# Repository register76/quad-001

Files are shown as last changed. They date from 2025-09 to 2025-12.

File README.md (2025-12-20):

<p align="center">
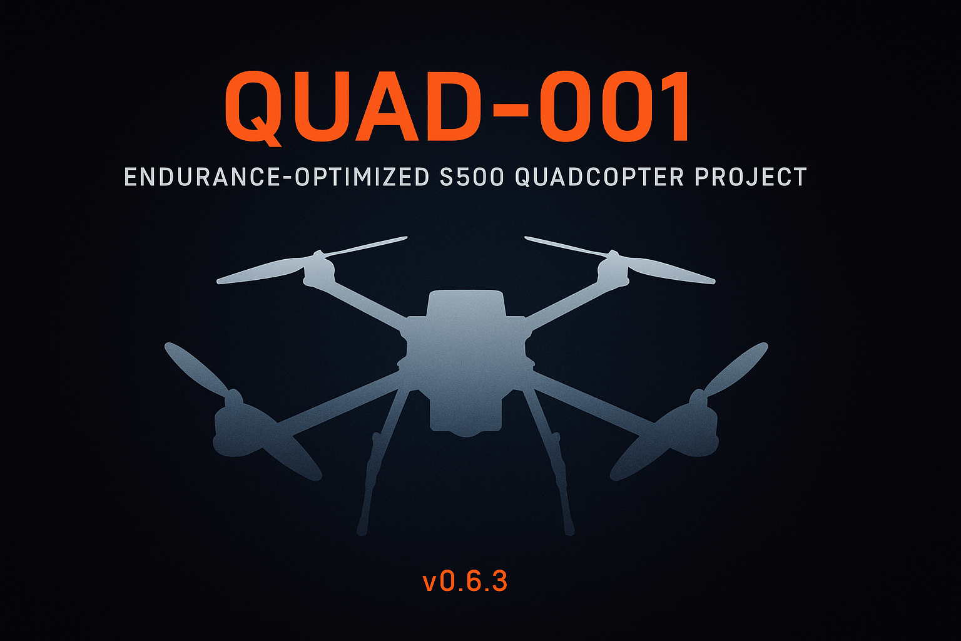
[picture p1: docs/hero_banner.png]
Quad-001 Hero Banner
  
</p>

<p align="center">
  
  
  
</p>

# Quad-001 — Endurance-Optimized S500 Quadcopter  
Version: **v0.6.3** (December 2025)

Quad-001 is a long-term engineering project to design, build, tune, and document a
high-efficiency 450–500 mm class quadcopter focused on endurance, stability,
and modular expandability. The project includes CAD parts, firmware configuration,
structural tuning, telemetry integration, and future autonomy and FPV improvements.

---

## 🛠️ Current Configuration (v0.6.3)

**Airframe**
- S500 frame (final decision locked)
- Carbon-fiber stiffeners + TPU/PLA vibration isolation
- Custom 4-piece landing-leg damper system
- New landing leg installed

**Propulsion**
- Motors: 3112-900 KV  
- Props: **APC 10 × 4.7** (current set installed)  
- Battery: 4S 5000 mAh LiPo  
- ESC: SkyStars KO60 BLHeli32 60A 4-in-1

**Flight Control**
- Matek H743-SLIM V3  
- GPS/Compass: HGLRC M100  
- Receiver: ExpressLRS RP4TD  
- Telemetry: **RFD900X** (MAVLink2, SERIAL6 @ 57 600 baud)

**Cameras / FPV (coming in v0.7)**
- Foxeer Razer Micro FPV camera  
- TBS Unify Pro32 HV VTX  
- Foxeer Lollipop Antenna  
- **RunCam Orange 5** (4K high-resolution recording camera)

---

## 🔗 Quick Component Reference (Web Links)

| Component | Model / Notes | Link |
|---|---|---|
| **Frame** | S500 500 mm frame | https://www.amazon.com/s?k=S500+frame |
| **Motors** | 3112-900KV | https://www.amazon.com/s?k=3112+900kv+motor |
| **Props** | APC 10×4.7 SF | https://www.apcprop.com/product/10x4-7sf-b4/ |
| **ESC** | Skystars KO60 4-in-1 BLHeli32 | https://www.amazon.com/s?k=skystars+ko60 |
| **Flight Controller** | Matek H743-SLIM V3 | http://www.mateksys.com/?portfolio=h743-slim |
| **GPS / Compass** | HGLRC M100 | https://www.hglrc.com/products/hglrc-m100-mini-m8n-gps |
| **Receiver** | ExpressLRS RP4TD | https://www.expresslrs.org/receivers/rp4td/ |
| **Transmitter (RC)** | Radiomaster Boxer | https://www.radiomasterrc.com/products/boxer-radio-controller |
| **Telemetry Radio** | RFD900X | https://store.rfdesign.com.au/rfd-900x/ |
| **FPV Camera** | Foxeer Razer Micro | https://www.foxeer.com/foxeer-mini-standard-razer-fpv-camera-g-266 |
| **VTX** | TBS Unify Pro32 HV | https://team-blacksheep.com/shop/pro32hv |
| **Antenna** | Foxeer Lollipop | https://www.amazon.com/s?k=foxeer+lollipop |
| **HD Camera** | **RunCam Orange 5** | https://shop.runcam.com/runcam-5-orange/ |
| **Companion Computer** | Rpanion (Pi-based) | https://www.rpanion.com/software/rpanion-server/ |
| **ArduPilot Firmware** | ArduCopter | https://firmware.ardupilot.org/Copter/stable/ |

---

## 🚁 Project Status Summary

Quad-001 is structurally complete and in the late-tuning phase for v0.6.x:

- New APC 10×4.7 props installed  
- All 4 dampers + new landing leg installed  
- First stable flight on 10×4.7 completed (v0.6.3 milestone)  
- RFD900X MAVLink link fully operational  
- Initial FFT analysis complete (fundamental ~86 Hz)  
- Preparing for notch tuning, altitude-loop refinement, and rate-loop steps

The aircraft is now optimized for clean logs and ready for advanced tuning.

---

## 🧪 Tuning Progress (v0.6.x)

**Completed**
- Hover tests with 10×4.7 props  
- Initial FFT → fundamental ~86 Hz  
- Basic position hold tuning  
- RFD900 integration for live tuning  
- Leg dampers & structural stiffening  
- Baseline logs for rate loops and altitude behavior  

**Upcoming**
- Update harmonic notch filter using new FFT  
- Altitude-loop refinement  
- Step-response rate-loop flights  
- Autotune  
- Post-Autotune filter + PID verification  

---

## 🎥 FPV Integration (v0.7 milestone)

Planned tasks:
- Wire Foxeer camera → H743  
- Install TBS Unify Pro32 HV  
- Install and tune Lollipop antenna  
- Noise + EMI validation  
- Ground station receiver testing  
- Action cam mounting tests for **RunCam Orange 5**

---

## 🧭 Autonomy & Sensors (v0.8 milestone)

- Downward LiDAR (TF-Luna I2C preferred)  
- Enhanced altitude hold  
- AUTO missions  
- RTL refinement  
- Speed-limit switches via PSC_ANGLE_MAX  
- Companion-computer extensions (Rpanion, MAVLink routing, future apps)

---

## 🧱 CAD / Mechanical Design

Custom-designed and parametric components include:

- Arm stiffeners (TPU → CF → PLA sandwich)  
- Landing gear dampers  
- GPS mast  
- Battery tray  
- RFD900 mounting hardware  
- Prop guard experiments for 1047 props  
- Camera mount designs, including **RunCam Orange 5** mounting options  

---

## 🎯 Roadmap

**v0.6.x — Structural & Tuning**
- ✔ Frame upgrade  
- ✔ RFD900 integration  
- ✔ New props + dampening  
- ✔ Notch tuning  
- ✔ Rate/altitude tuning  
- ☐ Autotune  

**v0.7 — FPV**
- ✔ Camera + VTX integration  
- ✔ Antenna work  
- ✔ Ground station receiver  
- ☐ Wiring cleanup  
- ☐ RunCam mount + test flights  

**v0.8 — Autonomy**
- ☐ Downward LiDAR  
- ☐ AUTO missions  
- ☐ Advanced RTL  
- ☐ Speed limits  
- ☐ Companion-computer apps  

---

## 🧵 Serial Ports

### 🧭 Matek H743-SLIM UART Reference Guide

[H743-SLIM V3 IO Mapping Documentation](https://www.mateksys.com/?portfolio=h743-slim#tab-id-5)

| **GPIO Port Label** | **FC PAD LABEL** | **Typical Use** | **ArduPilot SERIALx** | **Protocol (value)** | **Baud** | **Notes / Tips** |
|---|---|---|---|---|---|---|
| **USART1** | RX1/TX1 | 📈 Spare  | SERIAL2 | None (0) |  | Leave unused until you need it (set to device-specific later). |
| **USART2** | RX2/TX2 | 📡 GPS #1 | SERIAL3 | GPS (5)  | 230 | Pair with I²C compass on same GPS puck. |
| **USART3** | RX3/TX3 | 📈 Spare  | SERIAL4 | None (0) | | Leave unused until you need it (set to device-specific later). |
| **UART4**  | RX4/TX4 | 🛰 Telemetry / RFD900 | SERIAL6 | MAVLink (2) | 57 | Long-range radio. Provide dedicated 5 V ≥ 2 A BEC. |
| **USART6** | RX6/TX6 |  📈 Spare | SERIAL7 | None (0) |  | Leave unused until you need it (set to device-specific later).  |
| **UART7** | RX7/TX7 | 🎮 ELRS Receiver (CRSF) | SERIAL1 |  ELRS(23) | 420 | Express LRS (main receiver port). |
| **UART8** | RX8/TX8 | ESC Telemetry | SERIAL5 |  ESC Telemetry(16) | 115 | ESC Telemetry. |
| **USB**  | USB | 🔌 Ground Station | SERIAL0 | MAVLink (2) |  | Main setup + firmware loading port. |

---

## 📄 License

See `LICENSE` for details.

---

## ✨ Notes

Quad-001 is a long-term iterative engineering project.  
All CAD, firmware, wiring, and tuning details evolve alongside each milestone.

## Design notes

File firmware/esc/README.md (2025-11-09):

# ESC

This is the paramter files for ESC  

## How to program ESC
- Goto https://esc-configurator.com/
- Plug USB cable into FC or connect through RFD900
- Ensure SERVO_BLH_AUTO = 1 in Mission Planner Parameters
- Select COM port in esc-configurator.com

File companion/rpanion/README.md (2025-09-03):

# Rpanion Link

This project uses **Rpanion-Server** as the companion computer software for telemetry and video streaming on the Raspberry Pi.  

👉 Download the release version 0.11.0 for Raspberry Pi 3, 4, and ZERO2 here: [Rpanion-Server Release v0.11.0](https://github.com/stephendade/Rpanion-server/releases/download/v0.11.0/Rpanion-Server-0.11.0-RasPiOS.img.xz)

---

## Notes
- Tested with Raspberry Pi 3/4 and Pi Zero 2 W.  
- Integrates with ArduPilot over MAVLink.  
- Provides telemetry, video streaming, and WiFi hotspot functionality.  

For setup instructions, see the official [Rpanion source and documentation](https://github.com/stephendade/Rpanion-server).

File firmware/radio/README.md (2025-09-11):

# RadioMaster Boxer Backup

- Radio: RadioMaster Boxer
- EdgeTX: 2.x.x
- Protocol: CRSF (ExpressLRS)
- ELRS TX FW: x.y.z
- ELRS RX FW: x.y.z
- Typical Packet Rate: 250 Hz
- Model Match: (on/off)

## Contents
- `MODELS/` — model configs
- `RADIO/` — global radio settings
- `backups/boxer-backup.otx` — full EdgeTX Companion backup (optional)

## Restore
1. Copy `MODELS/` and `RADIO/` to SD card root, or
2. Use Companion → open `.otx` → Write to Radio.

⚠️ Binding phrase and Wi-Fi creds are not included for security.

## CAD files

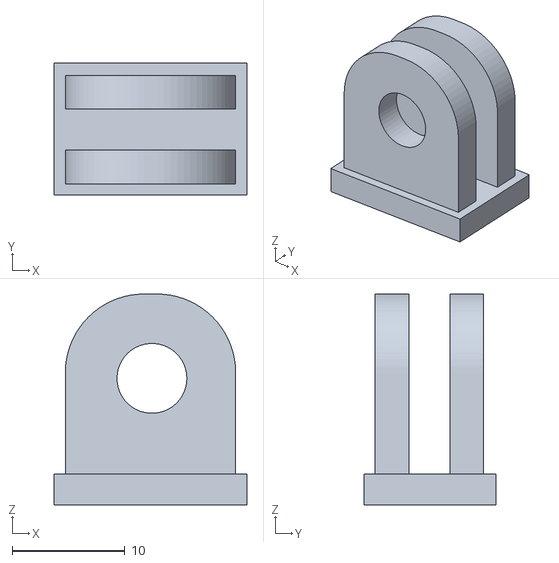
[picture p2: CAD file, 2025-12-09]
cad/openscad/2_prong.stl
17.1 x 11.8 x 18.8

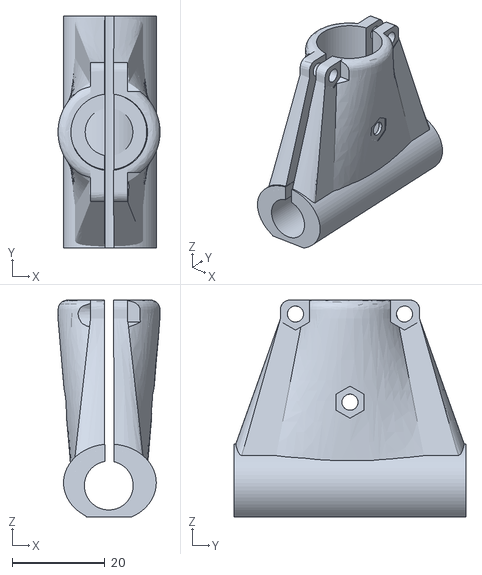
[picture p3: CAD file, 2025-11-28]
cad/stl/Landing_Gear_Tee_Remix.stl
22.0 x 50.0 x 46.7

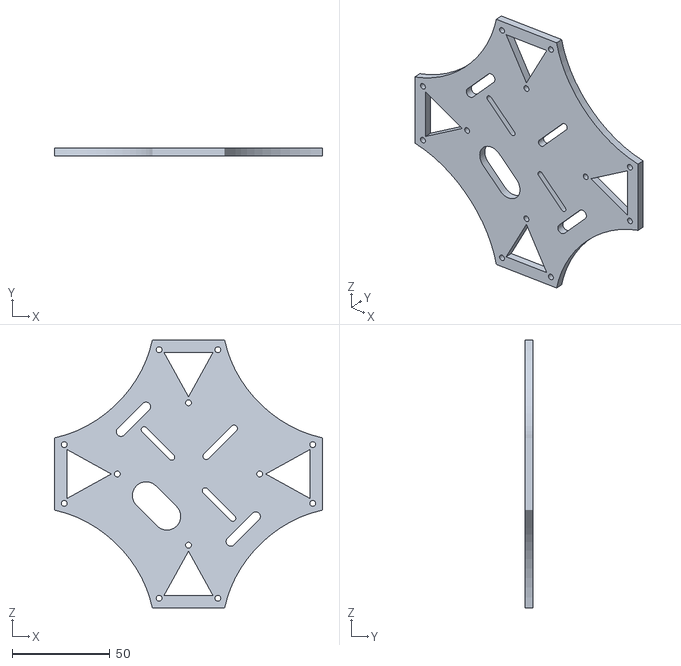
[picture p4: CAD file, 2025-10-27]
cad/openscad/top_frame_s500.STL
137.0 x 4.00 x 136.9

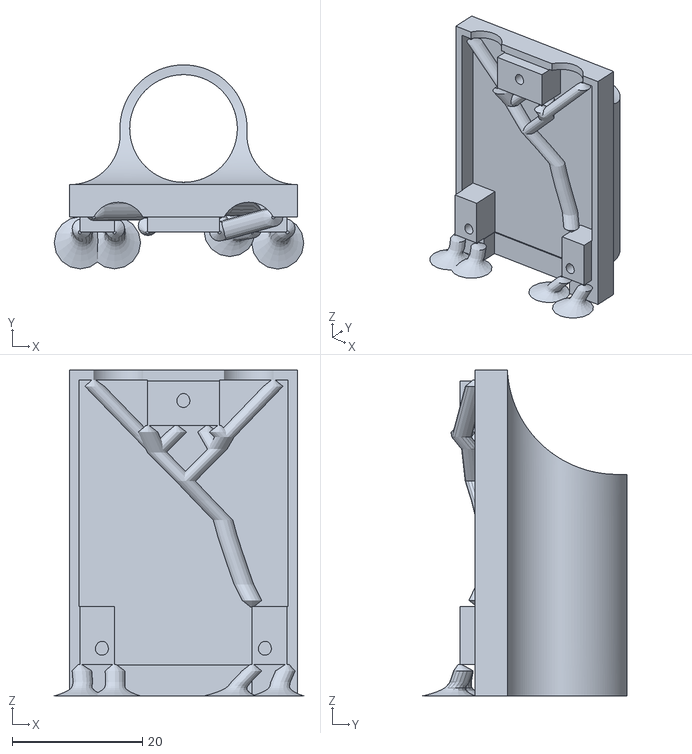
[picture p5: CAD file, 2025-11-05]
cad/stl/RFD900_16mm.stl
38.3 x 31.3 x 50.0

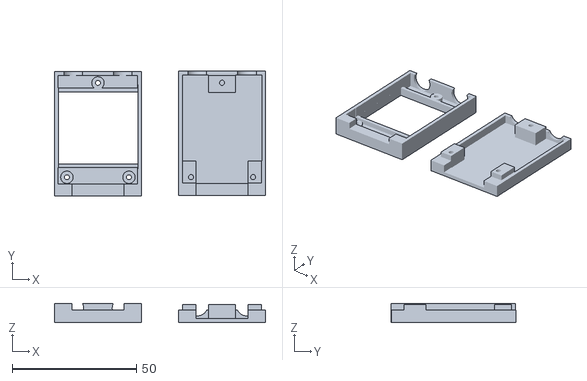
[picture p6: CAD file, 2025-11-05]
cad/stl/rfd900test.stl
85.0 x 50.2 x 7.75

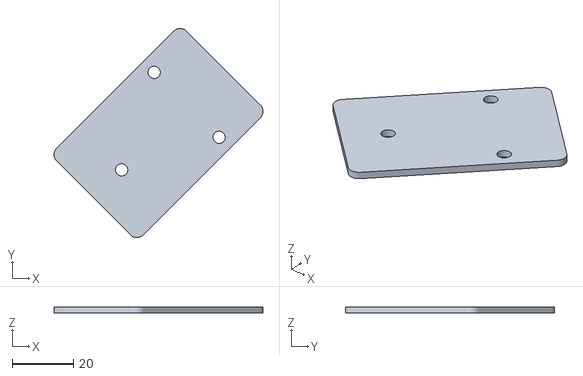
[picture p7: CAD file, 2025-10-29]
cad/stl/s500_cf_doublers.stl
68.2 x 68.2 x 2.00

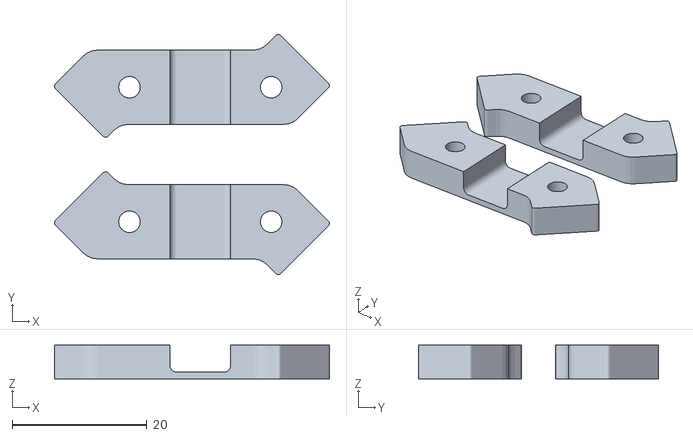
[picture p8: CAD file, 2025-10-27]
cad/stl/S500_Spacerv4.stl
40.7 x 35.6 x 5.00

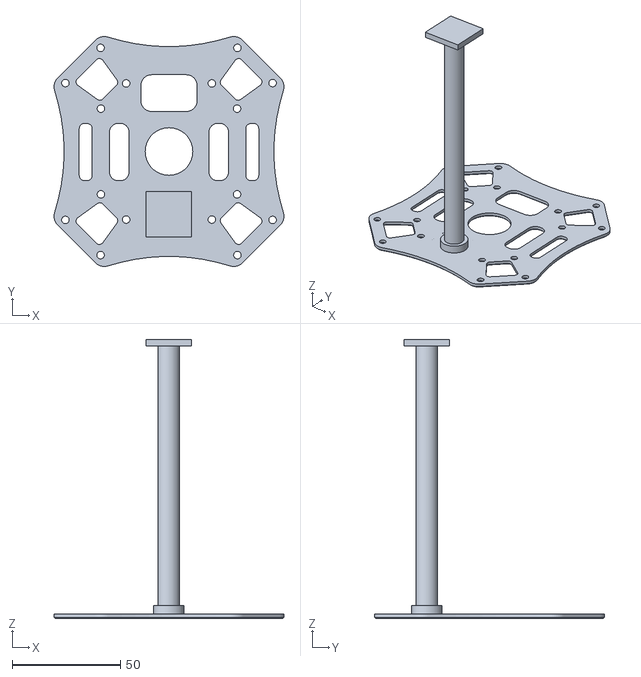
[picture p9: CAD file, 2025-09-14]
cad/stl/quad-001-union-mast-frame.stl
106.3 x 106.3 x 129.0

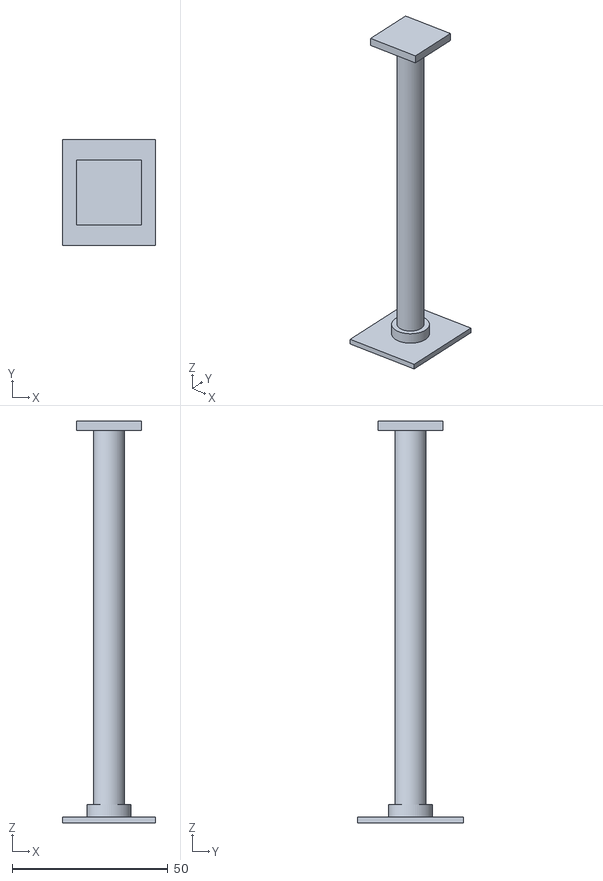
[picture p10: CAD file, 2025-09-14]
cad/stl/quad-001-gps_mast.stl
30.0 x 34.0 x 129.0

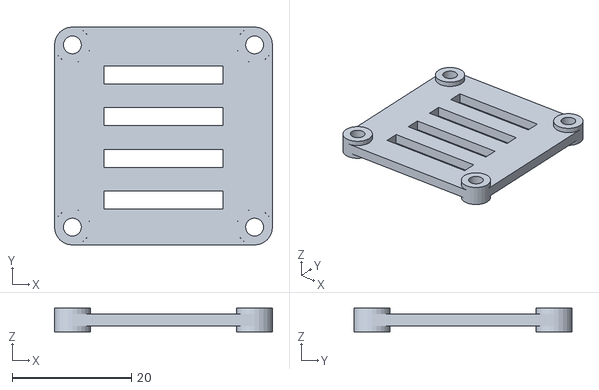
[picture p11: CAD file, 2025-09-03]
cad/stl/Flight_controller_mount_30x30_2-6.stl
36.5 x 36.5 x 4.00

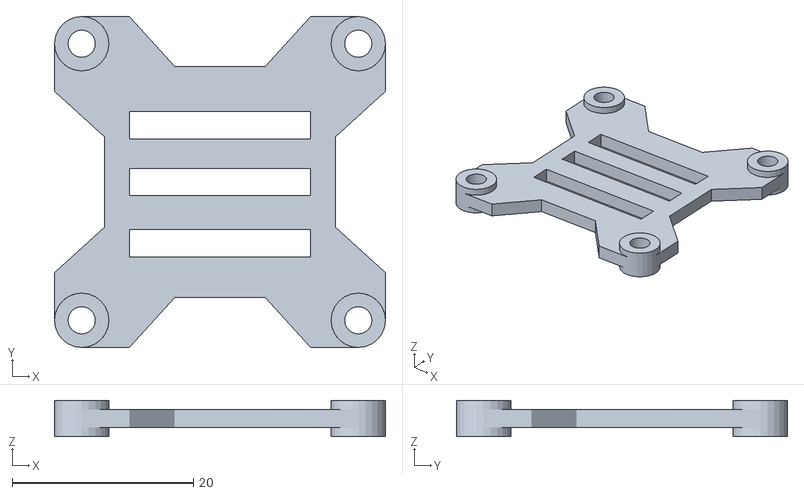
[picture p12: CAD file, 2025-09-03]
cad/stl/Flight_controller_mount_30x30_4-6.stl
36.5 x 36.5 x 4.00

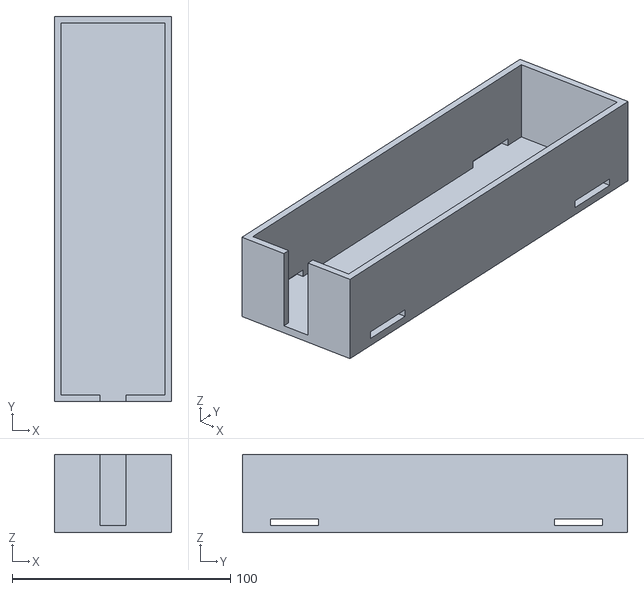
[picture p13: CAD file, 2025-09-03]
cad/stl/quad-001-battery_tray.stl
53.6 x 176.6 x 35.8

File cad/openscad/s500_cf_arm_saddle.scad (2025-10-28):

//
// S500 Arm Saddle (Bolt-On) — OpenSCAD
// Author: ChatGPT
// Version: v0.1 (2025-10-28)
// Purpose:
//   Two flat CF plates (top & bottom) that clamp the arm root using the existing 4-hole pattern.
//   Cut from 2.0 mm carbon fiber. No epoxy needed. Improves torsional stiffness.
//   Export each plate as DXF for CNC or print PLA first as a fit template.
//
// -------------------- User Parameters --------------------

export_mode       = "3D";   // "3D" or "DXF" (DXF outputs 2D outlines+holes only)
show_all_arms     = true;   // true: preview all four; false: preview one (arm_index)
arm_index         = 0;      // which arm to show when show_all_arms=false (0..3)

// Plate geometry
cf_thickness      = 2.0;    // mm
plate_len         = 60;     // mm (along arm axis)
plate_wid         = 40;     // mm (across arm axis)
corner_r          = 3.0;    // mm fillet for corners
kerf              = 0.10;   // mm (+ grows outline) for CNC compensation

// Holes (M3 recommended)
hole_d            = 4.0;    // mm (loose fit). If you want tighter, set to 3.2
slot_enable       = false;  // true -> slots in long direction
slot_d            = 3.2;    // slot width
slot_len          = 5.0;    // slot extra length (overall ~ hole_d + slot_len)

// Arm relief pocket (shallow recess on the inner face to hug the arm crown slightly)
relief_enable     = true;
relief_len        = 36;     // mm along arm
relief_wid        = 18;     // mm across arm
relief_depth      = 0.5;    // mm depth (keeps plate nearly full strength)
relief_round_r    = 2.0;    // corner fillet of relief

// Placement (reused from your good fit)
r_patch           = 50;                 // distance from board origin to plate center
arm_angles        = [45, 135, 225, 315];

// Hole pattern (XY offsets relative to plate center BEFORE rotation)
pattern_arm0      = [[-14,0],[13,-15],[13,15],[-13,0]];
pattern_arm1      = pattern_arm0;
pattern_arm2      = pattern_arm0;
pattern_arm3      = pattern_arm0;

// Optional: reference STL (for visual alignment only)
show_stl          = false;              // set true if you want to overlay your frame STL
stl_path          = "top_frame_s500.STL";
stl_alpha         = 0.25;
stl_rotate_deg    = [90,0,45];          // your earlier good orientation
stl_translate     = [-97.5, 0, 0];
stl_scale         = 1.0;

// -------------------- Helpers --------------------

function sel_pattern(i) =
    i==0 ? pattern_arm0 :
    i==1 ? pattern_arm1 :
    i==2 ? pattern_arm2 :
           pattern_arm3 ;

module rounded_rect_2d(w, h, r) {
    // Kerf in/out to keep fillets clean
    offset(delta=kerf) offset(delta=-kerf)
    hull() {
        translate([ w/2 - r,  h/2 - r]) circle(r=r, $fn=48);
        translate([-w/2 + r,  h/2 - r]) circle(r=r, $fn=48);
        translate([ w/2 - r, -h/2 + r]) circle(r=r, $fn=48);
        translate([-w/2 + r, -h/2 + r]) circle(r=r, $fn=48);
    }
}

module relief_2d(L, W, r) {
    // filleted inner pocket
    hull() {
        translate([ L/2 - r,  W/2 - r]) circle(r=r, $fn=36);
        translate([-L/2 + r,  W/2 - r]) circle(r=r, $fn=36);
        translate([ L/2 - r, -W/2 + r]) circle(r=r, $fn=36);
        translate([-L/2 + r, -W/2 + r]) circle(r=r, $fn=36);
    }
}

module hole_2d(d)    { circle(d=d, $fn=36); }
module slot_2d(d, L) {
    // Capsule slot along X
    hull() {
        translate([+L/2 - d/2, 0]) circle(d=d, $fn=36);
        translate([-L/2 + d/2, 0]) circle(d=d, $fn=36);
    }
}

module holes_2d(points) {
    for (p = points) translate(p)
        if (slot_enable) slot_2d(slot_d, hole_d + slot_len);
        else             hole_2d(hole_d);
}

// One plate outline with holes; if relief is enabled, subtract shallow recess on the "inner" face.
// We'll build TOP and BOTTOM from the same 2D and just extrude; relief direction is documented in notes.
module saddle_plate_2d(hole_pts) {
    difference() {
        rounded_rect_2d(plate_len, plate_wid, corner_r);
        holes_2d(hole_pts);
        if (relief_enable) // carve an internal pocket area
            relief_2d(relief_len, relief_wid, relief_round_r);
    }
}

module saddle_plate_3d(hole_pts) {
    linear_extrude(height=cf_thickness)
        saddle_plate_2d(hole_pts);
}

// Render one arm's top+bottom at its frame position
module arm_saddle_set(i) {
    angle = arm_angles[i];
    pts   = sel_pattern(i);
    // Position at arm root
    rotate([0,0,angle]) translate([r_patch,0,0]) {
        // TOP plate (put relief DOWN toward arm)
        color("black") translate([0,0, cf_thickness]) mirror([0,0,1]) saddle_plate_3d(pts);

        // BOTTOM plate (put relief UP toward arm)
        color("black") saddle_plate_3d(pts);

        // Optional visual markers:
        // translate([0,0,cf_thickness*1.8]) color([0,1,0]) cylinder(h=0.1,d=2,$fn=24); // plate center dot
    }
}

module all_saddles() {
    for (i=[0:len(arm_angles)-1]) arm_saddle_set(i);
}

module ref_stl() {
    color([0.1,0.6,1.0, stl_alpha])
        translate(stl_translate) rotate(stl_rotate_deg) scale(stl_scale)
            import(stl_path, convexity=5);
}

// -------------------- Scene --------------------

if (export_mode == "DXF") {
    // DXF export: choose TOP or BOTTOM—same outline; relief pocket shows so CAM can engrave 0.5 mm depth if desired.
    // Comment/uncomment the one you want to export at a time:
    projection(cut=true) saddle_plate_2d(pattern_arm0);
} else {
    if (show_stl) ref_stl();
    if (show_all_arms) {
        all_saddles();
    } else {
        arm_saddle_set(arm_index);
    }
}

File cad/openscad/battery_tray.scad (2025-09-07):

//
// Parametric battery tray with SIDE-WALL strap slots
// B Dog — Pi/quad build
//
// Coordinate frame:
//   X = width  (left↔right)
//   Y = length (front↔back)
//   Z = up (floor → lips)
//

//-------------------
// USER PARAMETERS 
//-------------------
battery           = [47, 170, 32];   // [W, L, H]  (width, length, height) in mm
clearance         = 0.30;            // per-side clearance inside pocket (ABS ≈ 0.3–0.4)
wallThickness     = 3.00;            // wall thickness
floorThickness    = 3.20;            // floor thickness

// Side-wall strap slots (two bands)
strapWidth       = 20.0;                // strap width (typical 20 mm)
slotLengthY      = strapWidth + 2.0;    // along Y (give ~1 mm per side)
slotThicknessZ   = 3.0;                 // vertical opening (Z) for the strap thickness
slot1OffsetFront = 10.0;                // first slot center from inner FRONT (Y)
slotSpacingY     = 130.0;               // distance between the two slots along Y

// Cable exit notch (front lip)
cableNotchWidth = 12.0;
cableNotchDepth = 6.0;

//-----------------------
// DERIVED GEOMETRY
//-----------------------
innerWidth  = battery[0] + 2*clearance;  // inner width
innerLength = battery[1] + 2*clearance;  // inner length 
innerHeight = battery[2] + 2*clearance;  // inner height

outerBlock = [ innerWidth  + 2*wallThickness,
               innerLength + 2*wallThickness, 
               innerHeight + floorThickness ];
              
//----------------
// MAIN SHAPES
//----------------
module tray_shell() 
{
  difference() 
  {
    // Outer block
    cube(outerBlock, center=false);

    // Inner pocket (removes volume, leaves floor + walls)
    translate([wallThickness, wallThickness, floorThickness])
    {
      cube([innerWidth, innerLength, innerHeight], center=false);
    }

    // FRONT cable notch (cut through front lip)
    translate([0.5*(outerBlock[0] - cableNotchWidth), 0.0, floorThickness])
    {
      cube([cableNotchWidth, cableNotchDepth, innerHeight], center=false);
    }
    
    // first slot from front
    translate([0.0, wallThickness + slot1OffsetFront, floorThickness])
    {
      cube([wallThickness, slotLengthY, slotThicknessZ], center=false);
      translate([wallThickness + innerWidth, 0.0, 0.0])
      {
        cube([wallThickness, slotLengthY, slotThicknessZ], center=false);
      }
      translate([0.0, slotSpacingY, 0.0])
      {
        cube([wallThickness, slotLengthY, slotThicknessZ], center=false);
        translate([wallThickness + innerWidth, 0.0, 0.0])
        {
          cube([wallThickness, slotLengthY, slotThicknessZ], center=false);
        }
      }
    }
  }
}

//---------------------
// ASSEMBLY
//---------------------
tray_shell();

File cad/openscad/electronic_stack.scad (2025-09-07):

// OpenSCAD — Parametric FC/ESC Stack Frame (30.5×30.5 + 35×35)
// Author: ChatGPT × B Dog
// License: CC0/Public Domain — tweak freely
//
// Includes additional 35×35 mm M3 hole pattern.
// All holes are plain through-holes (no heat-set pockets, no grommets).
// Plates are clean and flat (no integrated standoffs).

// ================ USER PARAMETERS =================
plate_thickness        = 3.0;    // mm
standoff_height_esc    = 7.0;    // base→ESC clearance
standoff_height_fc     = 10.0;   // ESC→FC clearance
edge_radius            = 2.0;    // outer corner rounding (2D)

// Stack & hardware
stack_spacing          = 30.5;   // Ardu/Betaflight standard
alt_stack_spacing      = 35.0;   // new hole pattern
mount_hole_d           = 3.2;    // for M3 screws

// Plate footprint
base_w                 = 45;
base_l                 = 45;
lip_overhang           = 2;

// Zip-tie slots
slot_w                 = 6.0;
slot_l                 = 22.0;
slot_margin            = 8.0;
slot_count_per_side    = 2;
use_zip_tie_slots      = false;

// Venting
vent_count             = 2;
vent_w                 = 6.0;
vent_gap               = 6.0;

// Aux shelf
use_aux_shelf          = false;
aux_spacing            = 20.0;
aux_w                  = 28.0;
aux_l                  = 36.0;
aux_offset             = [0, 32];
aux_thickness          = 2.5;

// Side guards
use_side_guards        = false;
side_guard_h           = 10.0;
side_guard_t           = 2.0;

$fn=64;

// ================ HELPERS =================
module rounded_plate(w,l,r,th){
  linear_extrude(th)
    minkowski(){
      square([w-2*r,l-2*r], center=true);
      circle(r);
    }
}

module rect_cut(c, sx, sy, h){ translate([c[0]-sx/2, c[1]-sy/2, 0]) cube([sx,sy,h+0.2], center=false); }
function stack_xy(i,spacing)=
  let(s=spacing/2)
  [ [ s,  s],
    [-s,  s],
    [-s, -s],
    [ s, -s] ][i];

// ================ FEATURES =================
module stack_holes(th){
  // main 30.5 mm pattern
  for(i=[0:3])
    translate([stack_xy(i,stack_spacing)[0], stack_xy(i,stack_spacing)[1], 0])
      cylinder(d=mount_hole_d, h=th+0.4);

  // additional 35 mm pattern
  for(i=[0:3])
    translate([stack_xy(i,alt_stack_spacing)[0], stack_xy(i,alt_stack_spacing)[1], 0])
      cylinder(d=mount_hole_d, h=th+0.4);
}


module vents(th){
  // vents centered along Y
  total = vent_count*vent_w + (vent_count-1)*vent_gap;
  y0 = -total/2 + vent_w/2;
  for(i=[0:vent_count-1]){
    y = y0 + i*(vent_w+vent_gap);
    rect_cut([0,y,0], base_w-2*slot_margin-6, vent_w, th);
  }
}

// ================ PLATES =================
module base_plate(){
  difference(){
    rounded_plate(base_w, base_l, edge_radius, plate_thickness);
    stack_holes(plate_thickness);
    if(use_zip_tie_slots) zip_tie_slots(slot_w, slot_l, plate_thickness);
    vents(plate_thickness);
  }
}

module esc_plate(){
  translate([0,0,plate_thickness + standoff_height_esc])
    difference(){
      rounded_plate(base_w - 2*lip_overhang, base_l - 2*lip_overhang, edge_radius, plate_thickness);
      stack_holes(plate_thickness);
      vents(plate_thickness);
    }
}

module fc_plate(){
  translate([0,0,plate_thickness + standoff_height_esc + plate_thickness + standoff_height_fc])
    difference(){
      rounded_plate(base_w - 2*lip_overhang, base_l - 2*lip_overhang, edge_radius, plate_thickness);
      stack_holes(plate_thickness);
      vents(plate_thickness);
    }
}

// ================ ASSEMBLY =================
module assembly(){
  color("lightgray") base_plate();
  color("gainsboro") esc_plate();
  color("whitesmoke") fc_plate();
}

// ================ PREVIEWS =================
assembly();

// ================ HOW TO EXPORT =================
// 1) Set 'assembly();' to show only the part you want (e.g., base_plate();)
// 2) Design → Render (F6)
// 3) File → Export → STL
// 
// Tuning Tips
// - For rubber isolation, print a second copy of base_plate() in TPU, trim to only the grommet_bosses() (or set a modifier),
//   then sandwich between frame and arms.
// - If using metal standoffs, set standoff heights to 0 and rely on hardware. 
// - The heat‑set pockets fit typical M3 inserts; tweak heatset_d/depth for your brand.

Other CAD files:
cad/openscad/fc_plate_30x30_heatset_rect_50x55_engraved.scad
cad/openscad/foxeer_case.scad
cad/openscad/gps_mast.scad
cad/openscad/rp4td_top_mount.scad
cad/openscad/s500_cf_doublers.scad

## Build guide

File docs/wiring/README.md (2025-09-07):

## Receiver → Flight Controller Wiring (RP4TD ↔ F405-HDTE)

| RP4TD Receiver Pin | Signal Type | FC Pad (Matek F405-HDTE) | Notes |
|---|---|---|---|
| **GND** | Ground | Any GND pad | Common ground |
| **VCC (5V)** | Power | 5V pad | Powers receiver |
| **TX** | CRSF signal | RX2 (UART2_RX) | Receiver → FC |
| **RX** | CRSF signal | TX2 (UART2_TX) | FC → Receiver |
| **ANT1 / ANT2** | Antennas | — | Mounted in 45° tubes |

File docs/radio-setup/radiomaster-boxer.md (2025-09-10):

# Radiomaster Boxer – ELRS Setup Notes

This document records the transmitter settings required to connect the **Radiomaster RP4TD ExpressLRS receiver** to the **Matek F405-HDTE** flight controller.

---

## Model Setup
1. Create a new model for **Quad-001**. 
2. In **Model Setup → External RF**:
  - **Mode** = CRSF 
  - **Baud** = 400k (default) 
3. Internal RF should be **off** (since we’re using the internal ELRS module). 

---

## ExpressLRS Lua Script
1. From the Boxer home screen, press **SYS → TOOLS**. 
2. Launch **ELRS.lua**. 
3. Verify connection to the RP4TD. 
4. Configure:
  - **Packet Rate** (default 150 Hz is fine to start). 
  - **Telemetry Ratio** (e.g. 1:4). 
  - **TX Power** (start low, e.g. 100 mW, for bench testing). 
  - **Binding**: use the Bind command here if receiver isn’t already paired. 

---

## Binding Notes
- First binding was completed successfully; receiver LED is **solid green** when linked. 
- Always power the transmitter **before** the quad. 
- Never run the RP4TD without antennas connected (u.FL connectors can burn out).

---

## Troubleshooting
- If Mission Planner shows no RC input:
  - Confirm **External RF = CRSF**. 
  - Ensure ELRS Lua script can connect to the module. 
  - Check that `SERIALx_PROTOCOL = 23` and `SERIALx_BAUD = 420000` are set on the flight controller.

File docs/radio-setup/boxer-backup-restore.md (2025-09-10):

# Boxer Backup & Restore

This guide explains how to back up and restore all **RadioMaster Boxer** settings, models, and SD card content. Keeping both copies ensures you can recover after firmware updates, SD card failures, or if you migrate to a new radio.

---

## 🔧 Backup with EdgeTX Companion (Models & Settings)

1. **Install Companion**  
   - Download [EdgeTX Companion](https://edgetx.org/download) for your OS.  
   - Install and open it.  

2. **Connect Boxer**  
   - On the Boxer:  
     - Long-press **SYS** → `Radio Setup` → `Hardware` tab.  
     - Set **USB Mode = CDC (Serial)**.  
   - Power-cycle radio.  
   - Plug into your PC with USB-C.  

3. **Read Models & Settings**  
   - In Companion, select radio profile = **RadioMaster Boxer**.  
   - Click **Read Models and Settings from Radio**.  
   - Save the `.otx` file (example: `Boxer_Backup_2025-09-09.otx`).  

👉 This captures:  
- All models  
- Inputs, mixes, outputs  
- Switch assignments  
- Telemetry screen setups  
- Global radio settings  

---

## 💾 Backup SD Card (Sounds, Scripts, Extras)

1. Power off Boxer.  
2. Remove SD card → insert into PC.  
3. Copy the entire SD card to a folder on your computer.  
   - Key folders:  
     - `/MODELS/` (model icons)  
     - `/RADIO/` (global settings)  
     - `/SCRIPTS/TOOLS/` (Lua scripts like ExpressLRS)  
     - `/SOUNDS/` (voice packs)  

👉 Store this folder alongside your `.otx` backup.  

---

## 🔄 Restore Process

1. **Models/Settings**  
   - Open Companion.  
   - Connect Boxer in **CDC mode**.  
   - Click **Write Models and Settings to Radio** → select your `.otx` backup.  

2. **SD Card Content**  
   - Copy saved SD card folders back onto a new or formatted card.  
   - Ensure firmware version and SD card pack version match (EdgeTX releases include matching SD packs).  

---

## 🛡️ Best Practices
- Backup before any firmware update.  
- Name files with date (`Boxer_Backup_YYYY-MM-DD.otx`).  
- Store one copy in your **GitHub repo** (private branch if preferred), and another in **cloud storage**.  
- Periodically test restoring to confirm backups are valid.

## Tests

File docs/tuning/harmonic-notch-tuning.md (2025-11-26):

# Harmonic Notch Tuning Guide (ArduPilot – Quad-001)

> **Version:** v1.0  
> **Applies to:** ArduPilot Copter 4.x+  
> **Vehicle:** Quad-001 (S500, 3112-900KV, 10×4.7 props)

This guide documents how to identify rotor vibration frequencies using FFT analysis and how to configure ArduPilot’s **Dynamic Harmonic Notch Filter** to suppress them.  
It includes the full workflow, recommended parameters, and annotated FFT screenshots.

## 📘 Overview

The **Harmonic Notch Filter** removes high-energy vibrations created by the propeller / motor system.  
Correct configuration:

- Reduces motor noise in the gyro signal  
- Improves PID tuning results  
- Allows higher rate gains without oscillation  
- Improves stability and efficiency  

This document walks through:

1. Pre-flight parameter setup  
2. Collecting hover data  
3. Using the ArduPilot FFT WebTool  
4. Identifying the rotor fundamental and harmonics  
5. Selecting the correct notch center, bandwidth, and reference throttle  
6. Verifying the result

## 🔧 1. Pre-Flight Parameter Setup

Ensure these parameters are set *before* collecting hover data:

```
LOG_BITMASK      = 131070     ; Log almost everything
FFT_ENABLE       = 1          ; Enable FFT logging
INS_LOG_BAT_OPT  = 2          ; Log raw IMU sensor data
INS_GYRO_FILTER  = 40–80 Hz   ; Standard gyro filter range
```

Reboot the flight controller after changing these.

## 🛫 2. Hover Data Collection Flight

Perform a short test flight:

1. Arm and take off.
2. Maintain **steady hover** for **20–30 seconds**.
3. Optionally do:
   - Small throttle variations  
   - A few gentle climbs  
4. Land and disarm.
5. Remove the SD card and obtain the `.BIN` file.

## 🌐 3. Analyze the Hover Log Using ArduPilot Web Tools

Open the official FFT analyzer:

👉 **https://firmware.ardupilot.org/Tools/WebTools/FilterReview/**

Steps:

- Upload your hover `.BIN` file  
- Select **Gyro 1** or **Gyro 2** (whichever is cleaner)  
- Set the hover time window  
- Click **Calculate**  
- View:
  - **IMU Spectrum** (frequency domain)
  - **IMU Spectrogram** (time vs frequency)

## 📊 4. Identify the Rotor Fundamental

Look for the **sharpest, narrowest, repeating peak** in the Pre-Filter traces.

A valid motor fundamental exhibits:

- A **distinct peak** at low frequency (often 50–200 Hz)  
- A **2× harmonic** exactly double the frequency  
- A **3× harmonic** triple the frequency  

Example from Quad-001:

```
Fundamental ≈ 86 Hz
2nd Harmonic ≈ 172 Hz
3rd Harmonic ≈ 258 Hz
```

## 🖼️ 5. Annotated Spectrum (Peaks & Harmonics)

Below is a labeled version of the FFT spectrum highlighting:

- Rotor fundamental (F₀)
- 2× harmonic
- 3× harmonic
- Notch filter location
- Pre- vs Post-filter response

> **Replace the placeholder image below with your actual plot.**  
> Keep the text labels — they match how ArduPilot FFT plots should be interpreted.

### 📌 Annotated Spectrum Example

```
+---------------------------------------------------------------+
|                                                               |
|   ^                                                           |
|   |                                      (3× Harmonic ~258Hz) |
| amplitude                                                    |
|   |                 (2× Harmonic ~172Hz)                     |
|   |     F₀ (Fundamental ~86Hz)                               |
|   |      ↓               ↓               ↓                   |
|   |     /|\             /|\             /|\                  |
|   |    / | \           / | \           / | \                 |
|   +--------------------------------------------------------->|
|                         frequency (Hz)                       |
+---------------------------------------------------------------+
```

### Markdown image embedding

```
![Annotated Spectrum](../images/notch-spectrum-annotated.png)
```

## 🎯 6. Configure the Harmonic Notch Filter

Using the identified fundamental (example: **86 Hz**):

```
INS_HNTCH_ENABLE = 1          ; Enable harmonic notch
INS_HNTCH_MODE   = 3          ; Throttle-based dynamic notch
INS_HNTCH_FREQ   = 86         ; Rotor fundamental frequency
INS_HNTCH_BW     = 40         ; Bandwidth (covers ~66–106 Hz)
INS_HNTCH_ATT    = 40         ; Attenuation strength
INS_HNTCH_HMNCS  = 3          ; Filter 1×, 2×, 3× harmonics
INS_HNTCH_REF    = <CTUN.ThO> ; Set to hover throttle value
```

Determine hover throttle:

Open the `.BIN` in Mission Planner and graph:

```
CTUN.ThO
```

Average during hover, e.g.:

```
INS_HNTCH_REF = 0.40
```

## 🔁 7. Verify the Notch Filter

Perform a second hover test. Upload the new `.BIN` to Filter Review again.

A correct notch will show:

- A **dip** in the Post-Filter traces at the fundamental  
- Reduced amplitude at 2× and 3× harmonics  
- No major shift in the fundamental frequency  
- No new oscillation peaks introduced  

If the Post-Filter dip is slightly off-center:

- Adjust `INS_HNTCH_FREQ` by ±5–10 Hz  
- Widen `INS_HNTCH_BW` if peak is broad  
- Narrow `BW` if sharp

## 🚀 8. Ready for Autotune

Once the notch filter is properly centered:

✔ Autotune (Roll → Pitch → Yaw)  
✔ Better rate tracking  
✔ Lower vibration  
✔ More stable hover/forward flight  

## 📎 Appendix: Quick Checklist

### Before Flight
- `FFT_ENABLE = 1`
- `INS_LOG_BAT_OPT = 2`
- SD card inserted

### During Flight
- Hold hover 20–30 seconds
- Avoid aggressive yaw

### After Flight
- Use Filter Review tool
- Identify sharp fundamental
- Configure notch

### Ideal Notch Behavior
- Post-filter dip on F₀  
- Harmonics suppressed  
- Lower noise floor

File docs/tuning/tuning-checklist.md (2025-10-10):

# Tuning Checklist (ArduCopter)  

A practical, step-by-step list you can print or check off during setup and flight testing.

---

## 0) Prep & Safety
- [ ] **Props off** for all bench configuration and spin tests.
- [ ] **Firmware current** (ArduCopter stable) and correct frame type (`FRAME_CLASS/TYPE`).
- [ ] **Radio failsafe** (RC + GCS) set to **RTL** and verified on bench.
- [ ] **Battery**: correct cell count & low-voltage failsafe (`BATT_*`) set.
- [ ] **Logging** enabled (`LOG_BITMASK` includes IMU, PID, RATE, CTUN, VIBE).

---

## 1) Mechanical & Wiring
- [ ] Motors correct order & direction; props marked with CW/CCW.  
- [ ] Arms, plates, and stack **tight**; ESC and FC **soft-mounted** as required.
- [ ] **CG** centered; battery/landing gear secure; wires strain-relieved.
- [ ] Antennas clear of carbon and power leads (RF + GPS hygiene).

---

## 2) Sensor Cal & Basic Params
- [ ] **Accel/Gyro** calibration complete; **compass** oriented & offsets sane.
- [ ] **RC calibration**: endpoints, trims at zero, channels mapped (RCMAP_*).
- [ ] **Flight modes** set (e.g., Stabilize, AltHold/Loiter, AutoTune on a switch).
- [ ] **ANGLE_MAX** conservative (e.g., 3000–3500 = 30–35°) for first tests.

---

## 3) ESC & Motor Checks
- [ ] **Protocol** set (DShot/OneShot/PWM) with correct min/max (`MOT_PWM_*`).
- [ ] **Motor test** in Mission Planner (props off) – verify each motor.
- [ ] **Hover throttle learn** (`MOT_HOVER_LEARN=2`) enabled for initial flights.

---

## 4) Vibration Baseline
- [ ] Short hover (calm air) and review **VIBE**: target **<15 m/s²** peaks, **<30** worst-case.  
- [ ] If high: add foam/gel, fix balance, reroute wires, stiffen structure.

---

## 5) Filters First (before gains)
### 5.1 Notch / Harmonic (with ESC RPM telemetry if available)
- [ ] Enable **Harmonic Notch** (`INS_HNTCH_ENABLE=1`).  
- [ ] Set source to **ESC RPM** or throttle as available (`INS_HNTCH_MODE`).  
- [ ] Set `INS_HNTCH_REF` (hover throttle) or RPM scaling; choose `INS_HNTCH_BW` ≈ **(center freq × 0.5)**.  
- [ ] Log a hover → verify notch centers on motor fundamental and harmonics. Adjust **center**, **BW**, **gain**.

### 5.2 Gyro/Accel filters
- [ ] **Gyro LPF** (`INS_GYRO_FILTER`) reasonable for prop size (e.g., 30–50 Hz for 10–11″ props).  
- [ ] **Accel LPF** (`INS_ACCEL_FILTER`) ~10–20 Hz typical.
- [ ] **Rate-loop LPFs**: `ATC_RAT_RLL_FLTT`, `ATC_RAT_PIT_FLTT` (start ~15–25 Hz for larger props),  
  and `ATC_RAT_*_FLTD` (start ~15–25 Hz). Yaw `FLTT/FLTD` often higher or default.

---

## 6) Initial Gains (safe starting point)
- [ ] Rate P/I modest (e.g., **0.10–0.15** on roll/pitch for 4S 4–5″ props; **lower** for big props).  
- [ ] Rate D small (e.g., **0.002–0.004** roll/pitch for big props).  
- [ ] Angle P (`ATC_ANG_RLL_P`, `ATC_ANG_PIT_P`) **4.0–6.0** to start on larger craft.  
- [ ] Yaw P/I low to moderate; **D=0** on yaw.

---

## 7) First Flights (manual check)
- [ ] **Stabilize**: quick hops; watch for overshoot/oscillation. Land & adjust **rate P/D**.  
- [ ] **AltHold/Loiter**: check position hold, stick feel (`ATC_INPUT_TC` ~0.15–0.25).  
- [ ] Verify hover throttle learned; set `MOT_THST_HOVER` if needed.

---

## 8) AutoTune (calm air, open space)
- [ ] Mode switch with **AutoTune** option configured.  
- [ ] Battery fresh; no wind/gusts; enough altitude.  
- [ ] Run **roll** first, then **pitch** (or both). If cross-coupling present, do axes separately.  
- [ ] After completion, test tuned PIDs (switch high/low per instructions).  
- [ ] If satisfied, **land with switch HIGH** to save; otherwise switch LOW to keep old PIDs.

---

## 9) Manual Refinement
- [ ] Review logs: **RATE** tracking, **D-term** activity, **vibes**.  
- [ ] If bounce-back on flips: lower **rate D** slightly or raise **FLTD** a bit.  
- [ ] If sluggish: increment **rate P** and **angle P** modestly (10–15% steps).  
- [ ] If mid-throttle oscillations: adjust **notch** (center/BW/gain) or reduce **rate D**.  
- [ ] For cross-coupling (pitch→roll): verify frame stiffness; consider **diagonal brace** before chasing gains.

---

## 10) Position & Velocity Controllers
- [ ] `PSC_VELXY_P/I/D` defaults are good; reduce **D** if twitchy in wind.  
- [ ] `LOIT_SPEED`, `WPNAV_SPEED`, `WPNAV_ACCEL` to match mission style.  
- [ ] Brake behavior: `LOIT_BRK_ACCEL`, `LOIT_BRK_JERK`, `PHLD_BRAKE_*` to taste.

---

## 11) Yaw Tuning
- [ ] Set `ATC_RAT_YAW_P/I` for crisp but stable heading; keep **D=0**.  
- [ ] If tail wags: lower **yaw P** and/or increase **FLTT** a bit.

---

## 12) EKF & Sensors
- [ ] **GPS** HDOP, Sats good; compass consistent; EKF innovations within bounds.  
- [ ] If RF/EMI suspected, reroute cables, add ferrites, separate radios and GPS.  
- [ ] Set `EK3_*` sources as intended (e.g., `EK3_SRC1_POSXY=3` for GPS).

---

## 13) Obstacle & Terrain (optional)
- [ ] Rangefinder/LiDAR configured (`RNGFND*`) with correct orientation.  
- [ ] Enable avoidance: `PRX_TYPE=RangeFinder`, `OA_TYPE=BendyRuler`, `AVOID_ENABLE=1`, set `AVOID_MARGIN`.

---

## 14) Telemetry & GCS
- [ ] RFD900 or Wi‑Fi telemetry stable; `SERIALx_BAUD` and MAVLink rates set.  
- [ ] Antennas oriented; link tested for dropouts.

---

## 15) Post-Flight Review
- [ ] Save a **param snapshot** after good flights.  
- [ ] Plot: **RATE** (desired vs actual), **CTUN.ThO**, **VIBE**, **ATT**, **IMU** clipping.  
- [ ] Note battery SAG; adjust mission speeds accordingly.

---

## 16) Finalize
- [ ] Tighten hardware, re‑route any chafing wires.  
- [ ] Threadlock where needed; add labels for ports/antenna orientation.  
- [ ] Print and insert this checklist into your field kit.

---

### Quick Reference: Typical Starting Filters (large props, calm)
- `INS_GYRO_FILTER`: 30–50 Hz  
- `INS_ACCEL_FILTER`: 10–20 Hz  
- `ATC_RAT_RLL/PIT_FLTT`: 15–25 Hz  
- `ATC_RAT_RLL/PIT_FLTD`: 15–25 Hz  
- Harmonic notch: enable; center = motor fundamental (from ESC RPM), BW ≈ 50% of center

> **Order of operations:** **Filters → Rate P/D → Angle P → Position/Yaw → Mission speeds**.  
> Make one change at a time; log every flight.

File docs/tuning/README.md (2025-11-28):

# Tuning & Flight Logs

[Tuning Tools](https://firmware.ardupilot.org/Tools/WebTools/)

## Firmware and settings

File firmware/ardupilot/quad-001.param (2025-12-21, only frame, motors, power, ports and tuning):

ATC_ANG_LIM_TC,1
ATC_ANG_PIT_P,16.12606
ATC_ANG_RLL_P,11.46049
ATC_ANG_YAW_P,6.804
ATC_ANGLE_BOOST,1
ATC_RAT_PIT_D,0.002572125
ATC_RAT_PIT_D_FF,0
ATC_RAT_PIT_FF,0
ATC_RAT_PIT_FLTD,18
ATC_RAT_PIT_FLTE,0
ATC_RAT_PIT_FLTT,20
ATC_RAT_PIT_I,0.07548285
ATC_RAT_PIT_IMAX,0.5
ATC_RAT_PIT_NEF,0
ATC_RAT_PIT_NTF,0
ATC_RAT_PIT_P,0.07548285
ATC_RAT_PIT_PDMX,0
ATC_RAT_PIT_SMAX,0
ATC_RAT_RLL_D,0.0017064
ATC_RAT_RLL_D_FF,0
ATC_RAT_RLL_FF,0
ATC_RAT_RLL_FLTD,18
ATC_RAT_RLL_FLTE,0
ATC_RAT_RLL_FLTT,20
ATC_RAT_RLL_I,0.0550717
ATC_RAT_RLL_IMAX,0.5
ATC_RAT_RLL_NEF,0
ATC_RAT_RLL_NTF,0
ATC_RAT_RLL_P,0.0550717
ATC_RAT_RLL_PDMX,0
ATC_RAT_RLL_SMAX,0
ATC_RAT_YAW_D,0
ATC_RAT_YAW_D_FF,0
ATC_RAT_YAW_FF,0
ATC_RAT_YAW_FLTD,20
ATC_RAT_YAW_FLTE,1.371195
ATC_RAT_YAW_FLTT,20
ATC_RAT_YAW_I,0.05106667
ATC_RAT_YAW_IMAX,0.5
ATC_RAT_YAW_NEF,0
ATC_RAT_YAW_NTF,0
ATC_RAT_YAW_P,0.5106667
ATC_RAT_YAW_PDMX,0
ATC_RAT_YAW_SMAX,0
ATC_RATE_FF_ENAB,1
ATC_RATE_P_MAX,0
ATC_RATE_R_MAX,0
ATC_RATE_Y_MAX,0
BATT_AMP_OFFSET,0
BATT_AMP_PERVLT,66.7
BATT_ARM_MAH,0
BATT_ARM_VOLT,14.7
BATT_CAPACITY,5000
BATT_CRT_MAH,0
BATT_CRT_VOLT,13.6
BATT_CURR_PIN,11
BATT_FS_CRT_ACT,2
BATT_FS_LOW_ACT,2
BATT_FS_VOLTSRC,0
BATT_LOW_MAH,0
BATT_LOW_TIMER,10
BATT_LOW_VOLT,14.4
BATT_MONITOR,4
BATT_OPTIONS,0
BATT_SERIAL_NUM,-1
BATT_VLT_OFFSET,0
BATT_VOLT_MULT,11
BATT_VOLT_PIN,10
BATT2_MONITOR,0
BATT3_MONITOR,0
BATT4_MONITOR,0
BATT5_MONITOR,0
BATT6_MONITOR,0
BATT7_MONITOR,0
BATT8_MONITOR,0
BATT9_MONITOR,0
FLTMODE_CH,8
FLTMODE_GCSBLOCK,0
FLTMODE1,16
FLTMODE2,0
FLTMODE3,0
FLTMODE4,2
FLTMODE5,0
FLTMODE6,0
FRAME_CLASS,1
FRAME_TYPE,1
INS_GYRO_FILTER,18
INS_HNTCH_ATT,40
INS_HNTCH_BW,40
INS_HNTCH_ENABLE,1
INS_HNTCH_FM_RAT,1
INS_HNTCH_FREQ,90
INS_HNTCH_HMNCS,3
INS_HNTCH_MODE,1
INS_HNTCH_OPTS,0
INS_HNTCH_REF,0.21
MOT_BAT_CURR_MAX,0
MOT_BAT_CURR_TC,5
MOT_BAT_IDX,0
MOT_BAT_VOLT_MAX,16.8
MOT_BAT_VOLT_MIN,13.2
MOT_BOOST_SCALE,0
MOT_HOVER_LEARN,2
MOT_OPTIONS,0
MOT_PWM_MAX,2000
MOT_PWM_MIN,1000
MOT_PWM_TYPE,6
MOT_SAFE_DISARM,0
MOT_SAFE_TIME,1
MOT_SLEW_DN_TIME,0
MOT_SLEW_UP_TIME,0
MOT_SPIN_ARM,0.07
MOT_SPIN_MAX,0.95
MOT_SPIN_MIN,0.09
MOT_SPOOL_TIM_DN,0
MOT_SPOOL_TIME,0.5
MOT_THST_EXPO,0.65
MOT_THST_HOVER,0.2061532
MOT_YAW_HEADROOM,200
SERIAL0_BAUD,115
SERIAL0_PROTOCOL,2
SERIAL1_BAUD,420
SERIAL1_OPTIONS,0
SERIAL1_PROTOCOL,23
SERIAL2_BAUD,57
SERIAL2_OPTIONS,0
SERIAL2_PROTOCOL,-1
SERIAL3_BAUD,230
SERIAL3_OPTIONS,0
SERIAL3_PROTOCOL,5
SERIAL4_BAUD,4
SERIAL4_OPTIONS,4
SERIAL4_PROTOCOL,37
SERIAL5_BAUD,115
SERIAL5_OPTIONS,0
SERIAL5_PROTOCOL,16
SERIAL6_BAUD,57
SERIAL6_OPTIONS,0
SERIAL6_PROTOCOL,2
SERIAL7_BAUD,57
SERIAL7_OPTIONS,0
SERIAL7_PROTOCOL,-1
SERIAL8_BAUD,115200
SERIAL8_OPTIONS,0
SERIAL8_PROTOCOL,-1
SERVO1_FUNCTION,36
SERVO1_MAX,2000
SERVO1_MIN,1000
SERVO1_REVERSED,0
SERVO1_TRIM,1000
SERVO2_FUNCTION,33
SERVO2_MAX,2000
SERVO2_MIN,1000
SERVO2_REVERSED,0
SERVO2_TRIM,1000
SERVO3_FUNCTION,34
SERVO3_MAX,2000
SERVO3_MIN,1000
SERVO3_REVERSED,0
SERVO3_TRIM,1000
SERVO4_FUNCTION,35
SERVO4_MAX,2000
SERVO4_MIN,1000
SERVO4_REVERSED,0
SERVO4_TRIM,1000
SERVO5_FUNCTION,0
SERVO5_MAX,1900
SERVO5_MIN,1100
SERVO5_REVERSED,0
SERVO5_TRIM,1500
SERVO6_FUNCTION,0
SERVO6_MAX,1900
SERVO6_MIN,1100
SERVO6_REVERSED,0
SERVO6_TRIM,1500
SERVO7_FUNCTION,0
SERVO7_MAX,1900
SERVO7_MIN,1100
SERVO7_REVERSED,0
SERVO7_TRIM,1500
SERVO8_FUNCTION,0
SERVO8_MAX,1900
SERVO8_MIN,1100
SERVO8_REVERSED,0
SERVO8_TRIM,1500
SERVO9_FUNCTION,0
SERVO9_MAX,1900
SERVO9_MIN,1100
SERVO9_REVERSED,0
SERVO9_TRIM,1500

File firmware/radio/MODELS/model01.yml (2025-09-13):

semver: 2.8.4
header: 
   name: "FPV DRONE"
timers: 
   0:
      start: 0
      swtch: "NONE"
      value: 0
      mode: OFF
      countdownBeep: 0
      minuteBeep: 0
      persistent: 2
      countdownStart: -1
      showElapsed: 0
      name: ""
telemetryProtocol: 0
thrTrim: 0
noGlobalFunctions: 0
displayTrims: 1
ignoreSensorIds: 0
trimInc: 0
disableThrottleWarning: 0
displayChecklist: 0
extendedLimits: 1
extendedTrims: 0
throttleReversed: 0
enableCustomThrottleWarning: 0
disableTelemetryWarning: 1
customThrottleWarningPosition: 0
beepANACenter: 0
mixData: 
 -
   weight: 100
   destCh: 0
   srcRaw: I0
   carryTrim: 0
   mixWarn: 0
   mltpx: ADD
   offset: 0
   swtch: "NONE"
   flightModes: 000000000
   delayUp: 0
   delayDown: 0
   speedUp: 0
   speedDown: 0
   name: ""
 -
   weight: 100
   destCh: 1
   srcRaw: I1
   carryTrim: 0
   mixWarn: 0
   mltpx: ADD
   offset: 0
   swtch: "NONE"
   flightModes: 000000000
   delayUp: 0
   delayDown: 0
   speedUp: 0
   speedDown: 0
   name: ""
 -
   weight: 100
   destCh: 2
   srcRaw: I2
   carryTrim: 0
   mixWarn: 0
   mltpx: ADD
   offset: 0
   swtch: "NONE"
   flightModes: 000000000
   delayUp: 0
   delayDown: 0
   speedUp: 0
   speedDown: 0
   name: ""
 -
   weight: 100
   destCh: 3
   srcRaw: I3
   carryTrim: 0
   mixWarn: 0
   mltpx: ADD
   offset: 0
   swtch: "NONE"
   flightModes: 000000000
   delayUp: 0
   delayDown: 0
   speedUp: 0
   speedDown: 0
   name: ""
 -
   weight: 100
   destCh: 4
   srcRaw: SC
   carryTrim: 0
   mixWarn: 0
   mltpx: REPL
   offset: 0
   swtch: "NONE"
   flightModes: 000000000
   delayUp: 0
   delayDown: 0
   speedUp: 0
   speedDown: 0
   name: "MODE -"
 -
   weight: 100
   destCh: 5
   srcRaw: SA
   carryTrim: 0
   mixWarn: 0
   mltpx: ADD
   offset: 0
   swtch: "NONE"
   flightModes: 000000000
   delayUp: 0
   delayDown: 0
   speedUp: 0
   speedDown: 0
   name: ""
 -
   weight: 100
   destCh: 6
   srcRaw: SD
   carryTrim: 0
   mixWarn: 0
   mltpx: ADD
   offset: 0
   swtch: "NONE"
   flightModes: 000000000
   delayUp: 0
   delayDown: 0
   speedUp: 0
   speedDown: 0
   name: "ARM-"
 -
   weight: 100
   destCh: 8
   srcRaw: SE
   carryTrim: 0
   mixWarn: 0
   mltpx: ADD
   offset: 0
   swtch: "NONE"
   flightModes: 000000000
   delayUp: 0
   delayDown: 0
   speedUp: 0
   speedDown: 0
   name: ""
 -
   weight: 100
   destCh: 9
   srcRaw: SF
   carryTrim: 0
   mixWarn: 0
   mltpx: ADD
   offset: 0
   swtch: "NONE"
   flightModes: 000000000
   delayUp: 0
   delayDown: 0
   speedUp: 0
   speedDown: 0
   name: ""
limitData: 
   0:
      min: 0
      max: 0
      ppmCenter: 0
      offset: 0
      symetrical: 0
      revert: 0
      curve: 32
      name: ""
   1:
      min: 0
      max: 0
      ppmCenter: 0
      offset: 0
      symetrical: 0
      revert: 1
      curve: 32
      name: ""
   3:
      min: 0
      max: 0
      ppmCenter: 0
      offset: 0
      symetrical: 0
      revert: 0
      curve: 32
      name: ""
   4:
      min: 0
      max: 0
      ppmCenter: 0
      offset: 0
      symetrical: 0
      revert: 0
      curve: 0
      name: "CH5"
expoData: 
 -
   mode: 3
   scale: 0
   trimSource: 0
   srcRaw: Ail
   chn: 0
   swtch: "NONE"
   flightModes: 000000000
   weight: 100
   name: ""
   offset: 0
   curve: 
      type: 1
      value: 0
 -
   mode: 3
   scale: 0
   trimSource: 0
   srcRaw: Ele
   chn: 1
   swtch: "NONE"
   flightModes: 000000000
   weight: 100
   name: ""
   offset: 0
   curve: 
      type: 1
      value: 0
 -
   mode: 3
   scale: 0
   trimSource: 0
   srcRaw: Thr
   chn: 2
   swtch: "NONE"
   flightModes: 000000000
   weight: 100
   name: ""
   offset: 0
   curve: 
      type: 1
      value: 0
 -
   mode: 3
   scale: 0
   trimSource: 0
   srcRaw: Rud
   chn: 3
   swtch: "NONE"
   flightModes: 000000000
   weight: 100
   name: ""
   offset: 0
   curve: 
      type: 1
      value: 0
 -
   mode: 3
   scale: 0
   trimSource: 0
   srcRaw: POT1
   chn: 3
   swtch: "NONE"
   flightModes: 000000000
   weight: 100
   name: ""
   offset: 0
   curve: 
      type: 1
      value: 0
 -
   mode: 3
   scale: 0
   trimSource: 0
   srcRaw: SC
   chn: 4
   swtch: "NONE"
   flightModes: 000000000
   weight: 100
   name: "MODE"
   offset: 0
   curve: 
      type: 1
      value: 0
 -
   mode: 3
   scale: 0
   trimSource: 0
   srcRaw: POT1
   chn: 4
   swtch: "NONE"
   flightModes: 000000000
   weight: 100
   name: ""
   offset: 0
   curve: 
      type: 1
      value: 0
curves: 
   31:
      type: 1
      smooth: 0
      points: -1
      name: "CNT"
points: 
   155:
      val: -100
   158:
      val: 100
   159:
      val: -2
   160:
      val: 2
flightModeData: 
   0:
      trim: 
         2:
            value: 4
            mode: 0
         3:
            value: 2
            mode: 0
      name: ""
      swtch: "NONE"
      fadeIn: 0
      fadeOut: 0
      gvars: 
         0:
            val: 0
         1:
            val: 0
         2:
            val: 0
         3:
            val: 0
         4:
            val: 0
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

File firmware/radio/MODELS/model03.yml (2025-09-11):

semver: 2.8.4
header: 
   name: "HELI"
timers: 
   0:
      start: 210
      swtch: "SA2"
      value: 210
      mode: ON
      countdownBeep: 2
      minuteBeep: 1
      persistent: 2
      countdownStart: -1
      showElapsed: 0
      name: ""
telemetryProtocol: 0
thrTrim: 0
noGlobalFunctions: 0
displayTrims: 1
ignoreSensorIds: 0
trimInc: 0
disableThrottleWarning: 0
displayChecklist: 0
extendedLimits: 0
extendedTrims: 0
throttleReversed: 0
enableCustomThrottleWarning: 0
disableTelemetryWarning: 0
customThrottleWarningPosition: 0
beepANACenter: 0
mixData: 
 -
   weight: 100
   destCh: 0
   srcRaw: I0
   carryTrim: 0
   mixWarn: 0
   mltpx: ADD
   offset: 0
   swtch: "NONE"
   flightModes: 000000000
   delayUp: 0
   delayDown: 0
   speedUp: 0
   speedDown: 0
   name: ""
 -
   weight: 100
   destCh: 1
   srcRaw: I1
   carryTrim: 0
   mixWarn: 0
   mltpx: ADD
   offset: 0
   swtch: "NONE"
   flightModes: 000000000
   delayUp: 0
   delayDown: 0
   speedUp: 0
   speedDown: 0
   name: ""
 -
   weight: 100
   destCh: 2
   srcRaw: I2
   carryTrim: 0
   mixWarn: 0
   mltpx: REPL
   offset: 0
   swtch: "SD0"
   flightModes: 000000000
   curve: 
      type: 3
      value: 1
   delayUp: 0
   delayDown: 0
   speedUp: 0
   speedDown: 0
   name: ""
 -
   weight: 100
   destCh: 2
   srcRaw: I2
   carryTrim: 0
   mixWarn: 0
   mltpx: REPL
   offset: 0
   swtch: "SD2"
   flightModes: 000000000
   curve: 
      type: 3
      value: 3
   delayUp: 0
   delayDown: 0
   speedUp: 0
   speedDown: 0
   name: ""
 -
   weight: 100
   destCh: 3
   srcRaw: I3
   carryTrim: 0
   mixWarn: 0
   mltpx: ADD
   offset: 0
   swtch: "NONE"
   flightModes: 000000000
   delayUp: 0
   delayDown: 0
   speedUp: 0
   speedDown: 0
   name: ""
 -
   weight: 100
   destCh: 4
   srcRaw: SB
   carryTrim: 0
   mixWarn: 0
   mltpx: ADD
   offset: 0
   swtch: "NONE"
   flightModes: 000000000
   delayUp: 0
   delayDown: 0
   speedUp: 0
   speedDown: 0
   name: ""
 -
   weight: 100
   destCh: 5
   srcRaw: I2
   carryTrim: 0
   mixWarn: 0
   mltpx: REPL
   offset: 0
   swtch: "SD0"
   flightModes: 000000000
   curve: 
      type: 3
      value: 4
   delayUp: 0
   delayDown: 0
   speedUp: 0
   speedDown: 0
   name: ""
 -
   weight: 100
   destCh: 5
   srcRaw: I2
   carryTrim: 0
   mixWarn: 0
   mltpx: REPL
   offset: 0
   swtch: "SD2"
   flightModes: 000000000
   curve: 
      type: 3
      value: 5
   delayUp: 0
   delayDown: 0
   speedUp: 0
   speedDown: 0
   name: ""
limitData: 
   0:
      min: 0
      max: 0
      ppmCenter: 0
      offset: 0
      symetrical: 0
      revert: 1
      curve: 32
      name: ""
   1:
      min: 0
      max: 0
      ppmCenter: 0
      offset: 0
      symetrical: 0
      revert: 0
      curve: 32
      name: ""
   3:
      min: 0
      max: 0
      ppmCenter: 0
      offset: 0
      symetrical: 0
      revert: 1
      curve: 32
      name: ""
expoData: 
 -
   mode: 3
   scale: 0
   trimSource: 0
   srcRaw: Ail
   chn: 0
   swtch: "NONE"
   flightModes: 000000000
   weight: 100
   name: ""
   offset: 0
   curve: 
      type: 1
      value: 50
 -
   mode: 3
   scale: 0
   trimSource: 0
   srcRaw: Ele
   chn: 1
   swtch: "NONE"
   flightModes: 000000000
   weight: 100
   name: ""
   offset: 0
   curve: 
      type: 1
      value: 50
 -
   mode: 3
   scale: 0
   trimSource: 0
   srcRaw: Thr
   chn: 2
   swtch: "NONE"
   flightModes: 000000000
   weight: 100
   name: ""
   offset: 0
   curve: 
      type: 1
      value: 0
 -
   mode: 3
   scale: 0
   trimSource: 0
   srcRaw: Rud
   chn: 3
   swtch: "NONE"
   flightModes: 000000000
   weight: 100
   name: ""
   offset: 0
   curve: 
      type: 1
      value: 50
curves: 
   0:
      type: 0
      smooth: 0
      points: 0
      name: "T1"
   1:
      type: 0
      smooth: 0
      points: 0
      name: "T2"
   2:
      type: 0
      smooth: 0
      points: 0
      name: "T3"
   3:
      type: 0
      smooth: 0
      points: 0
      name: "P1"
   4:
      type: 0
      smooth: 0
      points: 0
      name: "P2"
   5:
      type: 0
      smooth: 0
      points: 0
      name: "P3"
   31:
      type: 1
      smooth: 0
      points: -1
      name: "CNT"
points: 
   0:
      val: -100
   1:
      val: -10
   2:
      val: 30
   3:
      val: 70
   4:
      val: 100
   5:
      val: 60
   6:
      val: 60
   7:
      val: 60
   8:
      val: 60
   9:
      val: 60
   10:
      val: 75
   11:
      val: 75
   12:
      val: 75
   13:
      val: 75
   14:
      val: 75
   15:
      val: -20
   16:
      val: -10
   18:
      val: 28
   19:
      val: 50
   20:
      val: -50
   21:
      val: -24
   23:
      val: 24
   24:
      val: 50
   25:
      val: -50
   26:
      val: -24
   28:
      val: 24
   29:
      val: 50
   155:
      val: -100
   158:
      val: 100
   159:
      val: -2
   160:
      val: 2
customFn: 
   0:
      swtch: "SA0"
      func: OVERRIDE_CHANNEL
      def: "2,-100,1"
   1:
      swtch: "SF2"
      func: RESET
      def: "Tmr1,1"
thrTraceSrc: Thr
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

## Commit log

2025-07-30 Added initial BOM.
    [quad-001-bom.xlsx]
2025-07-30 Updated BOM.
    [quad-001-bom.xlsx]
2025-09-03 Added battery tray 3d print files.
    [battery_tray.scad, battery_tray.stl]
2025-09-03 Updated BOM with new flight controller and ESC.
    [quad-001-bom.xlsx]
2025-09-03 Added flight controller and ESC mounting stl files.
    [Flight_controller_mount_30x30_2-6.stl, Flight_controller_mount_30x30_4-6.stl]
2025-09-03 Moved BOM to docs folder and updated README.md.
    [quad-001-bom.xlsx]
2025-09-04 Added ESC parameters.
2025-09-04 Updated FC parameters.
    [quad-001.param]
2025-09-04 Updated fc parameters file to use DSHOT-600.
    [quad-001.param]
2025-09-04 Saved fc parameters after accelerometer calibration.
    [quad-001.param]
2025-09-04 Corrected ESC direction parameters.
    [quad-001.param]
2025-09-07 Added wiring folder.
2025-09-07 Added electronic stack and rp4td scad drauings.
    [battery_tray.scad, electronic_stack.scad, rp4td_top_mount.scad]
2025-09-10 Updated parameters after integrating RC Controller and Receiver.
    [quad-001.param]
2025-09-11 Updated FC parameters after bench testing prior to first flight.
    [quad-001.param]
2025-09-13 Ardupilot params after first flight.
    [quad-001.param]
2025-09-14 Added GPS to README and updated cad files.
    [gps_mast.scad, quad-001-battery_tray.stl, quad-001-gps_mast.stl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]
2025-09-20 Updates after adding GPS and radio telemetry screens on Radio Master Boxer transmitter.
    [quad-001.param]
2025-09-21 FC Arducopter parameters after gps flight. This flight had successful position hold.
    [quad-001.param]
2025-09-23 Moved Arm to latching switch less likely to trigger accidentally. Added BRAKE mode. Added AUTO-TUNE mode.
    [quad-001.param]
2025-09-27 Updated ESC firmware enabling telemetry.
2025-10-26 Added missions, firmware, and scad files.
    [fc_plate_30x30_heatset_rect_50x55_engraved.scad]
2025-10-27 Added stl 3d print files and corrected arducopter firmware version.
    [S500_Spacerv4.stl, top_frame_s500.STL]
2025-10-27 Updated ESC settings as part of S500 upgrade.
2025-10-27 More ESC updates for S500 build.
2025-10-28 S500 parameter updates.
    [quad-001.param]
2025-10-28 Added links to 3d printed parts.
2025-10-28 Updates after gettting RC receiver to work on S500 frame.
    [quad-001.param]
2025-10-28 Updated cad files to latest on laptop in preparation for laptop replacement.
    [gps_mast.scad, s500_cf_arm_saddle.scad, s500_cf_doublers.scad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]
2025-10-29 Updated cad files.
    [s500_cf_doublers.scad, s500_cf_doublers.stl]
2025-11-05 Added rfd900 case for mounting on 16 mm leg tubing.
    [RFD900_16mm.stl, rfd900test.stl]
2025-11-07 Updated ESC info in README.
2025-11-07 Updated arducopter parameters after installing new Skystars ESC.
    [quad-001.param]
2025-11-07 Updates after getting RFD900 connection.
    [quad-001.param]
2025-11-09 Successful bench test.
    [quad-001.param]
2025-11-09 Added Brake Mode.
    [quad-001.param]
2025-11-15 v0.6.3 tuning results.
    [quad-001-bom.xlsx, quad-001.param]
2025-11-26 Tuning updates from Harmonic Notch Filter.
    [quad-001.param]
2025-11-28 Added S500 landing gear bracket.
    [Landing_Gear_Tee_Remix.stl]
2025-11-28 Current tuning parameters.
    [quad-001.param]
2025-12-09 Added recent scad files.
    [2_prong.stl, foxeer_case.scad]
2025-12-14 Tuning updates after adding cameras and fine tuning harmonic notch filter.
    [quad-001.param]
2025-12-19 Parameters prior to auto tuning.
    [quad-001.param]
2025-12-19 Parameters after autotuning pitch and roll.
    [quad-001.param]
2025-12-21 yaw tuning upstes.
    [quad-001.param]
